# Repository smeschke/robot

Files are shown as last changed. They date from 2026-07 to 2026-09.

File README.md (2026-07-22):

Robot Platform 🛠️

Modular ESP32-based robot platform for outdoor navigation, motor control, and sensor integration.

This is a human-scale, differential-drive utility robot designed to move comfortably through real-world, ADA-compliant spaces at walking speed.

I chose 10-inch pneumatic tires so the robot can handle sidewalks, ramps, and grass reliably without suspension. The motors, gearboxes, and battery come from ride-on toys—they're inexpensive, readily available, and deliver excellent torque at low speeds.

The robot is controlled by an ESP32. The ESP32 uses ESPNOW to communicate with a manual joystick, or a computer. This allows the user to switch from 'auto' to 'manual' without touching any cords.

🔧 Technical Snapshot

The robot uses 550-type brushed DC motors with 100:1 reduction gearboxes driving 10-inch pneumatic wheels. It's powered by 12-volt, 7 amp-hour sealed lead-acid battery(s). Motor control is handled by BTS7960 H-bridge motor drivers.

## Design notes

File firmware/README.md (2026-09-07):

# Firmware ⚡

Arduino sketches for every ESP32 in the system — a sketch for each of the controllers, and a sketch for each of the boards on the robot. All of it is plain Arduino with no libraries beyond `esp_now.h` (plus a display library for the dual stick's screen). Everything talks ESP-NOW on channel 1, no encryption, packet types distinguished purely by length.

## Sketches

| Sketch | Flashes onto | Does |
|---|---|---|
| [`single_analog_stick_espnow.ino`](single_analog_stick_espnow.ino) | single stick controller | Streams drive packets every 5 ms |
| [`skidsteer_espnow.ino`](motor_receiver.ino) | robot — motor board | Arcade-mixed skid steer on four BTS7960 channels, with ramping and a 300 ms fail-safe stop |

## Setup

Standard ESP32 Arduino toolchain — install the ESP32 board package, pick your board, flash over USB. The controllers flash through the same USB-C port that powers them, no disassembly.

The only per-build configuration is MAC addresses: controllers send to hardcoded peers, so flash the robot boards first, grab each board's MAC from the serial monitor at boot, and paste them into the controller sketch (`robotMac` in the single stick; `motorMac` and `relayMac` in the dual stick). The robot boards need no controller config — they auto-register whichever controller they hear first.

Wiring diagrams, BOMs, and protocol documents are in [`build_documents/`](../build_documents/).

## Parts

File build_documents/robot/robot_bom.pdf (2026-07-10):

E S P - N O W C O N T R O L P R O T O C O L · T E A R D O W N C O N V E N T I O N

# Robot — Bill of Materials

ROBOT

4×10" differential-drive base

Part | Qty | Unit Cost | Total Cost
550-size 12V gearmotor (~100W) | 4 | $18.00 | $72.00
BTS7960 (IBT-2) H-bridge driver | 4 | $7.00 | $28.00
10" pneumatic tire + hub | 4 | $14.00 | $56.00
12V 7Ah SLA battery | 2 | $20.00 | $40.00
ESP32 receiver board (ESP-NOW) | 1 | $6.00 | $6.00
Frame/chassis stock, fasteners | 1 | $30.00 | $30.00
Wiring/fusing/connectors | 1 | $10.00 | $10.00
Total Build Cost | | | $242.00

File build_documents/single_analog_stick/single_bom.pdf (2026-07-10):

E S P - N O W C O N T R O L P R O T O C O L · T E A R D O W N C O N V E N T I O N

# Single Analog Stick Controller — Bill of Materials

CONTROLLER 1

Minimal one-way sender — drive + lights

Part | Qty | Unit Cost | Total Cost
ESP32 DevKit V1 (or XIAO-C3) | 1 | $6.00 | $6.00
KY-023 joystick module | 1 | $2.00 | $2.00
3D printed enclosure (PLA) | 1 | $2.00 | $2.00
Wire/connectors/hardware | 1 | $3.00 | $3.00
Total Build Cost | | | $13.00

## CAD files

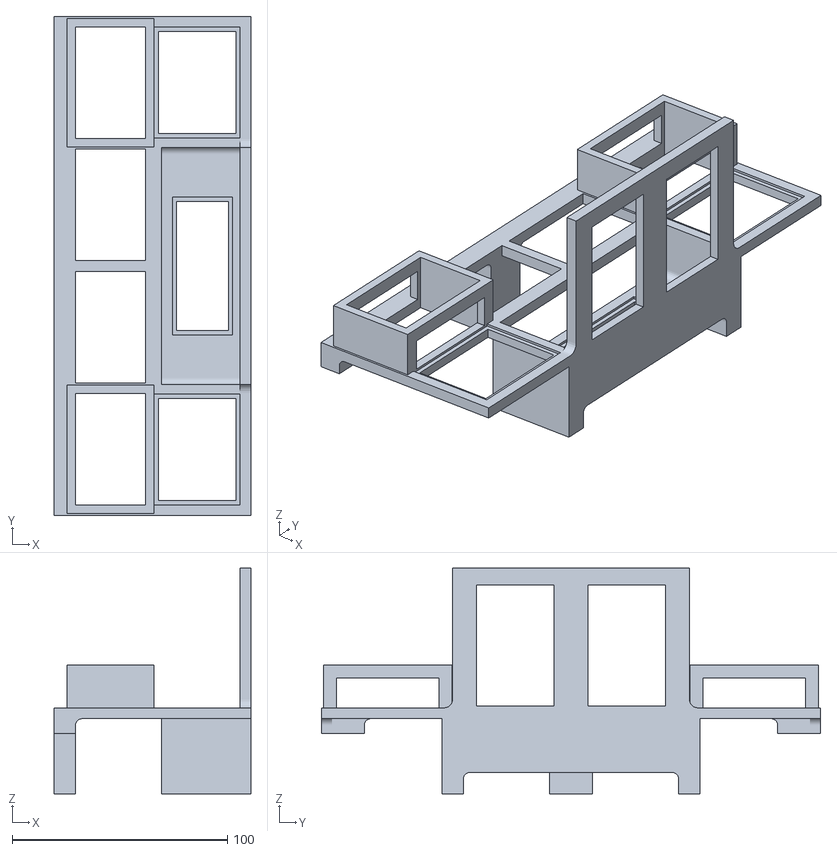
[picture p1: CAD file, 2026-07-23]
build_documents/robot/driver_board.stl
91.5 x 232.0 x 105.0

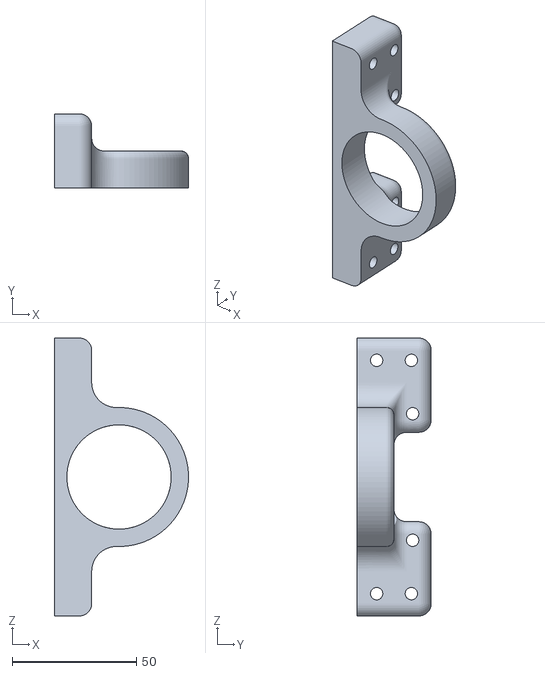
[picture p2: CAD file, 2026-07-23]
build_documents/robot/wheel_mount.stl
54.0 x 30.0 x 112.0

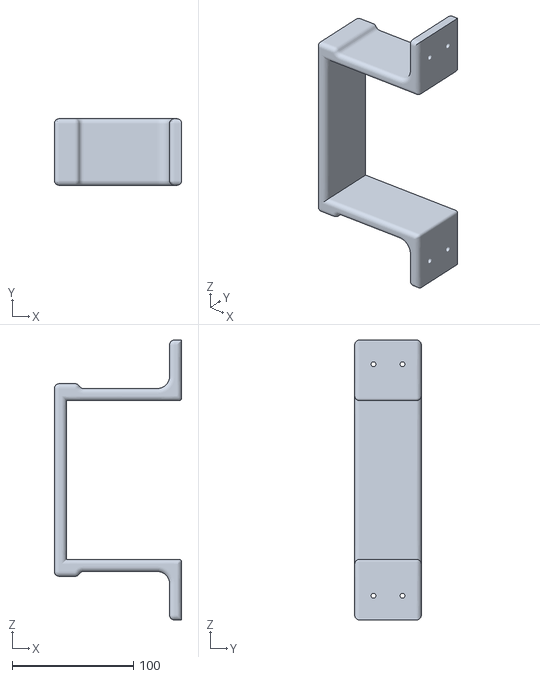
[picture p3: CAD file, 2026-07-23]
build_documents/robot/battery_holder.stl
105.0 x 55.0 x 231.0

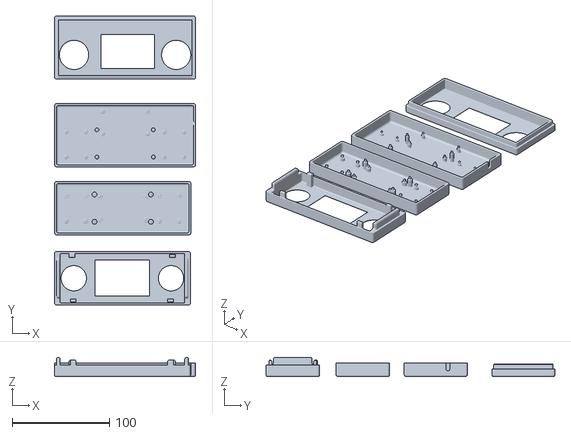
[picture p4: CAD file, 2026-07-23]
build_documents/robot/dual_joystick_controller_2_inch_screen.stl
145.3 x 297.0 x 20.0

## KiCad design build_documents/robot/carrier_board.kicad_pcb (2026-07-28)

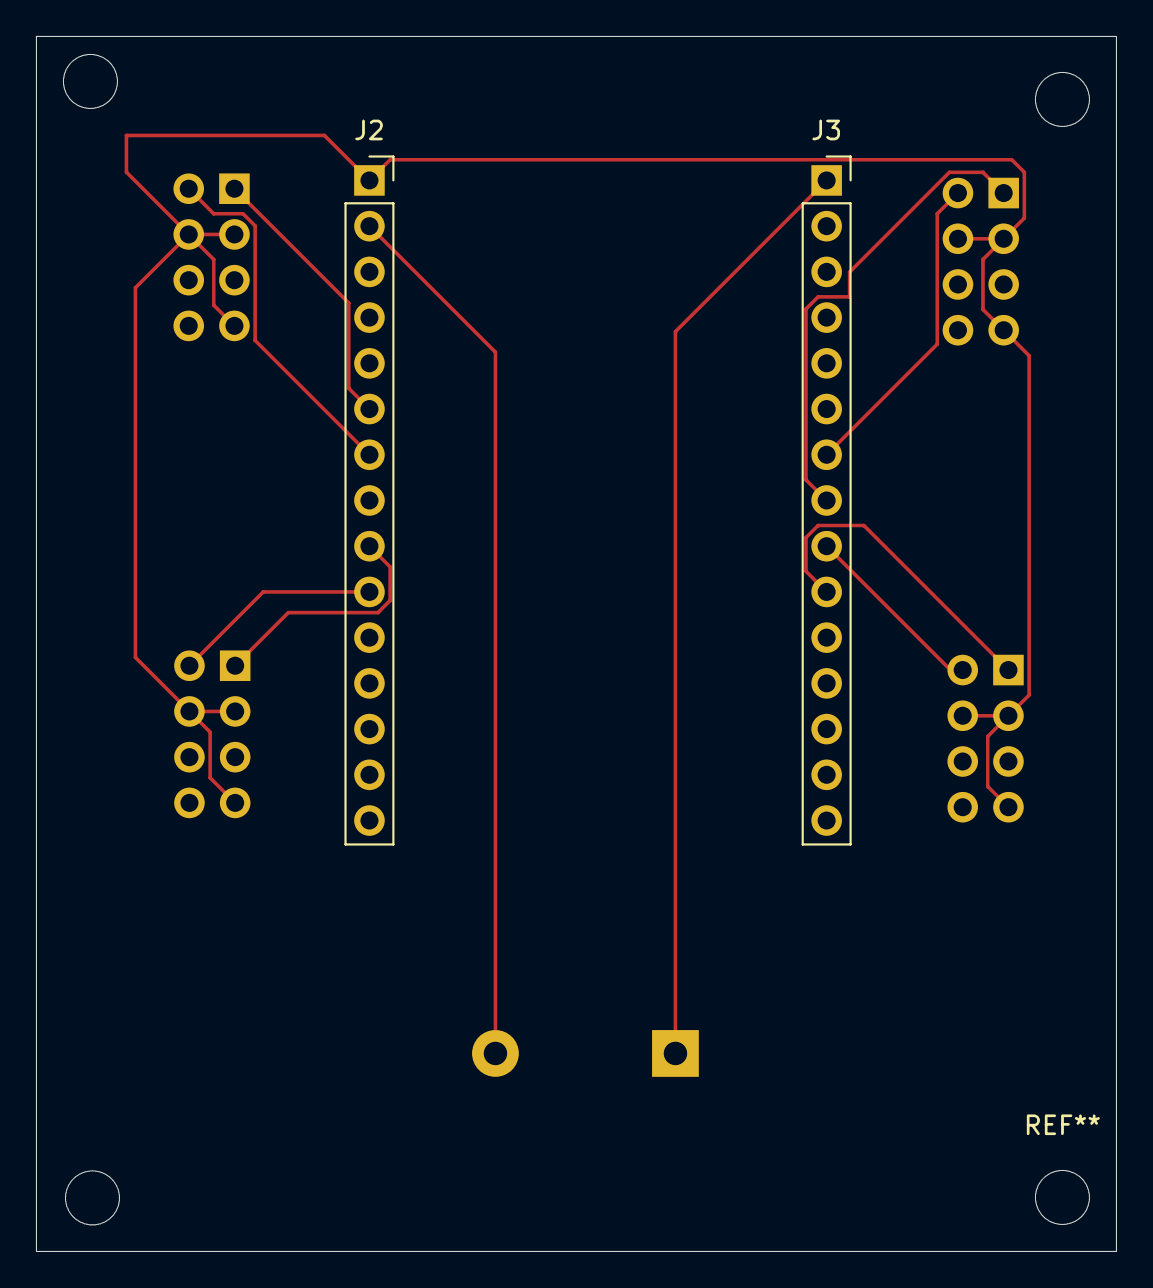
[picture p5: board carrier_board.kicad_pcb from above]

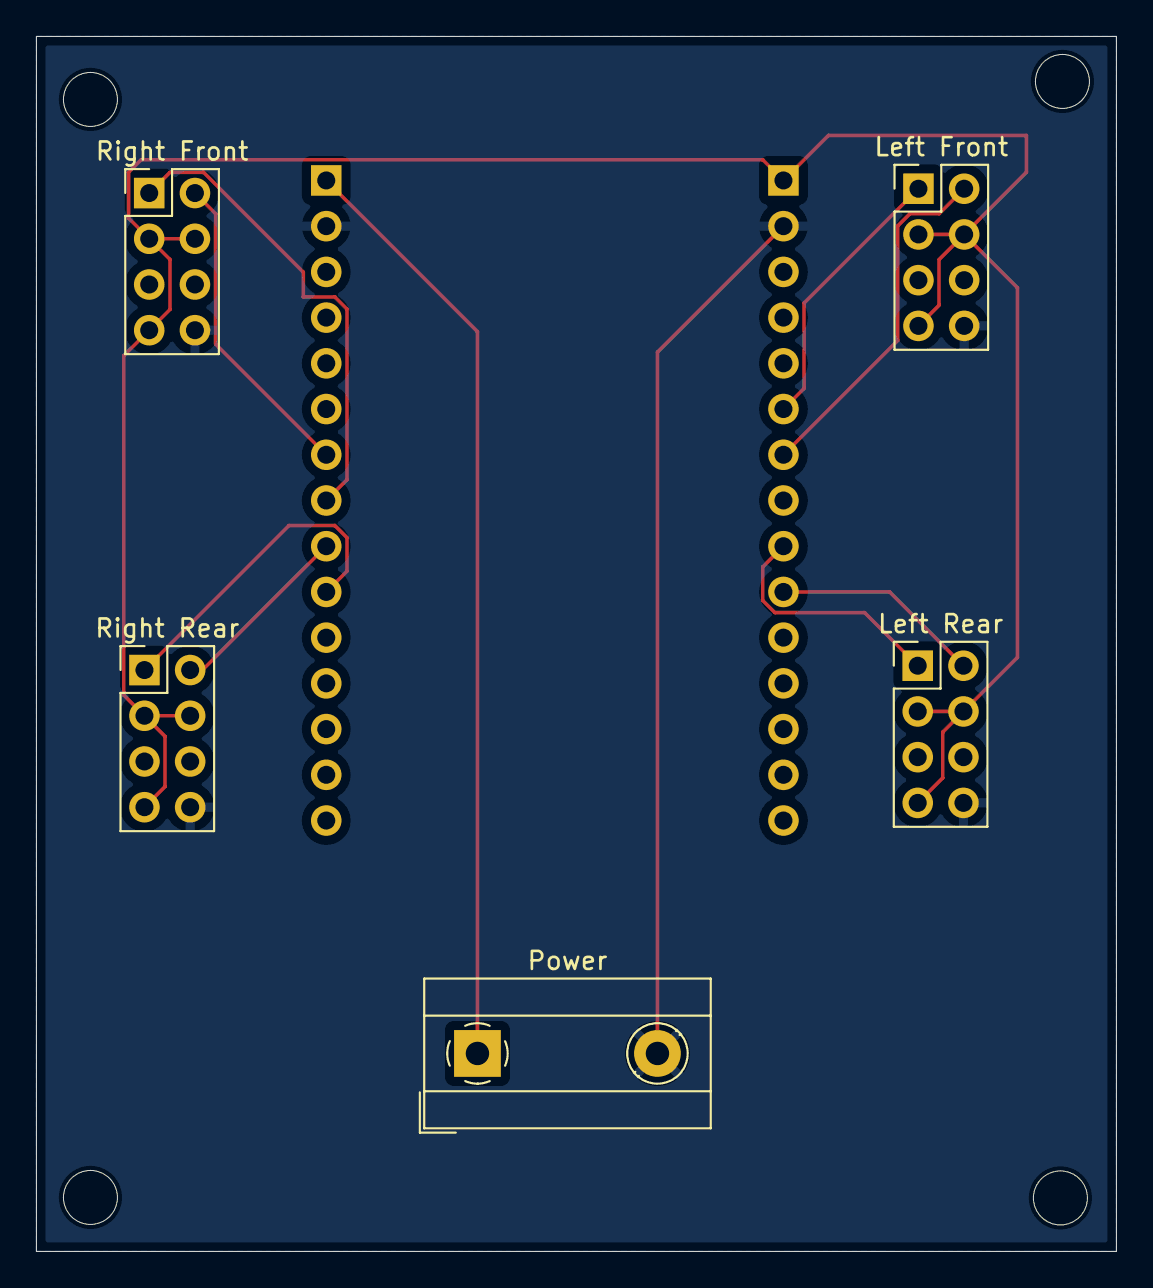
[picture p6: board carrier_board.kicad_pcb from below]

Board: 2 copper layers, 60.0 x 67.5 mm, 7 parts (5 on the bottom side), 11 nets.

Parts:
J2, J3: Conn_01x15; PinSocket_1x15_P2.54mm_Vertical
Left Front: Conn_02x04_Odd_Even; PinHeader_2x04_P2.54mm_Vertical
Left Rear: Conn_02x04_Odd_Even; PinHeader_2x04_P2.54mm_Vertical
Power: Screw_Terminal_01x02; TerminalBlock_MetzConnect_Type067_RT01902HDWC_1x02_P10.00mm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
Right Front: Conn_02x04_Odd_Even; PinHeader_2x04_P2.54mm_Vertical
Right Rear: Conn_02x04_Odd_Even; PinHeader_2x04_P2.54mm_Vertical

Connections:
/+3V3: J2.1, Left Front.3, Left Front.4, Left Front.7, Left Rear.3, Left Rear.4, Left Rear.7, Right Front.3, Right Front.4, Right Front.7, Right Rear.3, Right Rear.4, Right Rear.7
/+5V: J3.1, Power.1
/GND: J2.2, J3.2, Left Front.8, Left Rear.8, Power.2, Right Front.8, Right Rear.8
/GPIO16: J2.6, Left Front.1
/GPIO17: J2.7, Left Front.2
/GPIO18: J2.9, Left Rear.1
/GPIO19: J2.10, Left Rear.2
/GPIO25: J3.8, Right Front.1
/GPIO26: J3.7, Right Front.2
/GPIO32: J3.10, Right Rear.1
/GPIO33: J3.9, Right Rear.2

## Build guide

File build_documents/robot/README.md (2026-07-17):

# The Robot 🤖

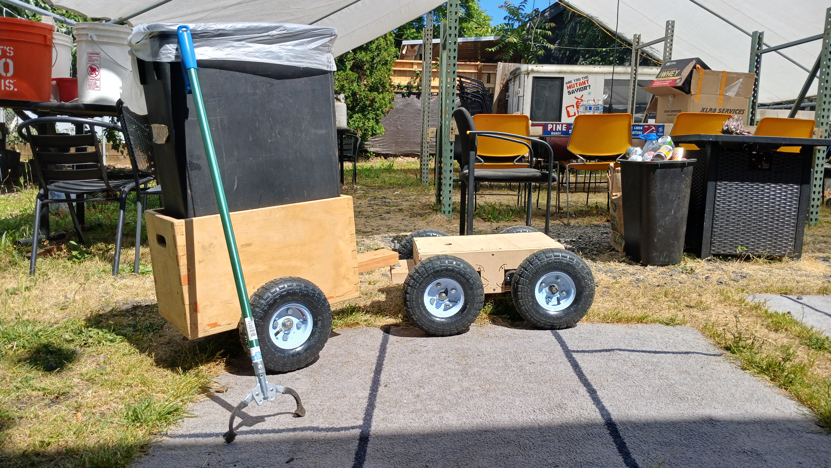
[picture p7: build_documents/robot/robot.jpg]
robot


Human-scale differential-drive utility robot built from ride-on toy parts: 550-type brushed motors with 100:1 gearboxes on 10-inch pneumatic wheels, powered by 12 V 7 Ah sealed lead-acid, driven by BTS7960 H-bridges. Ride-on toy drivetrains are cheap, everywhere, and geared for exactly this job — high torque at walking speed. The pneumatic tires handle sidewalks, ramps, and grass without any suspension, and it'll tow a cart.

## Architecture

There's no single robot brain — it's two independent ESP32s, each listening on ESP-NOW:

- **Motor board** ([`firmware/skidsteer_espnow.ino`](../../firmware/skidsteer_espnow.ino)) — receives the drive stream, does the skid-steer mixing, runs four BTS7960 channels.
- **Relay board** ([`firmware/relay_receiver.ino`](../../firmware/relay_receiver.ino)) — receives light events, drives two relays (left/right lights) for latched headlights and 2-second momentary turn signals.

Receivers tell packets apart purely by length (12-byte drive, 5-byte light event), so both boards can share the airwaves without a header byte or any routing. Anything that speaks the protocol can drive it — the single stick, the dual stick, or a computer through a reflashed controller — and switching between manual and auto control never involves touching a cord.

## Drive behavior

The motor board turns the joystick stream into arcade-mixed skid steer (throttle ± turn), with two safety behaviors worth knowing:

- **Fail-safe stop.** If no drive packet arrives for 300 ms, targets go to zero. The controller streams every 5 ms, so this only trips when the link is actually gone.
- **Ramping.** Motor output moves toward the target 1 PWM count every 3 ms (~0 to full in 0.75 s), so a stick flick doesn't dump full torque into the drivetrain — and the fail-safe stop is a controlled ramp-down, not a faceplant.

There's also a ~20% stick deadzone in the mixer, so the robot stays genuinely still at center.

## Lights

The relay board latches headlights on/off and fires momentary turn signals, deduping the controller's burst-resends by sequence number. A turn signal on one side never touches the other side's relay, and when it expires the relay reverts to the headlight state. Every ~500 ms it sends a heartbeat back (RSSI, relay state, uptime) — that's what feeds the dual stick controller's HUD. Controllers are auto-registered: first packet heard from a MAC becomes the peer, no pairing step.

## Build docs

- [Bill of materials](robot_bom.pdf)
- [Wiring diagram](robot_wiring_diagram.png)
- [Protocol details](robot_protocol.pdf)
- [STL files](stl_for_robot.md)

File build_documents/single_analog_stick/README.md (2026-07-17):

# Single Analog Stick Controller 🕹️

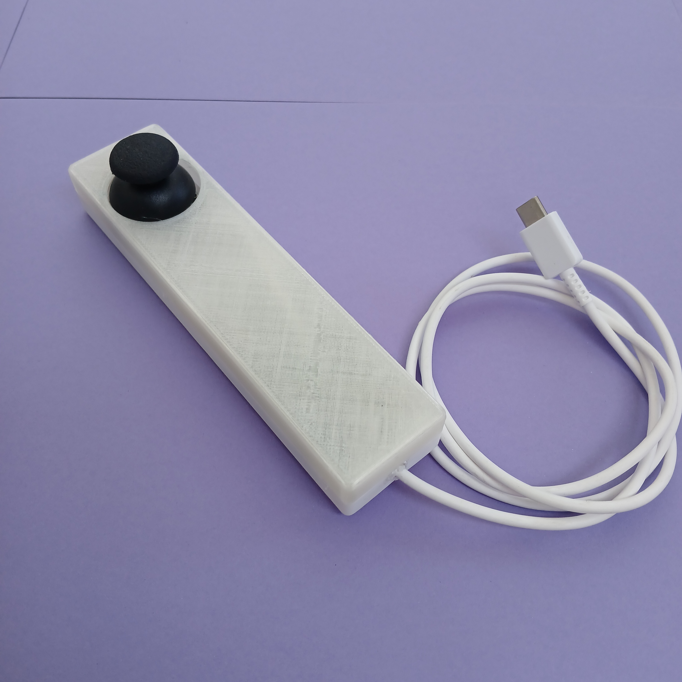
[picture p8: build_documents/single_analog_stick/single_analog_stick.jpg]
single analog stick controller


One-handed controller for the robot: an ESP32, an analog thumbstick, and a 3D-printed enclosure. Thumb handles steering and throttle; clicking the stick cycles the speed cap 25% → 50% → 75% → 100%. Driving one-handed leaves your other hand free to load items onto the robot, hold a coffee, or open doors.

There's no onboard battery — the controller runs off its USB-C cable, so plug it into a pocket USB battery pack in the field, or any phone charger at the bench.

## USB-C goes straight to the ESP32

The USB-C port is wired to the ESP32's USB interface, not just power. Plug the controller into a computer and you have serial and flashing access — no disassembly, no test pads, no jig. So:

- Reflash it as a serial-to-ESP-NOW bridge and drive the robot from any computer that can open a serial port. Flash the stock firmware back when done.
- Need an ESP32 for a minute? This is one, in a case.

## Protocol

ESP-NOW, channel 1, addressed to the robot's MAC. Packets every 5 ms:

```c
typedef struct __attribute__((packed)) {
  uint16_t x;    // 0–4095, center 2048
  uint16_t y;    // 0–4095, center 2048
  uint32_t seq;  // packet counter
  uint32_t ms;   // sender uptime
} JoyPacket;
```

Stick auto-centers on boot, ±40-count deadband. Speed scaling happens sender-side, so the packet carries final values and the robot firmware stays simple. `seq`/`ms` let the receiver drop stale packets.

Firmware is ~100 lines of plain Arduino, no libraries beyond `esp_now.h`: [`firmware/single_analog_stick_espnow.ino`](../../firmware/single_analog_stick_espnow.ino). Retarget it by changing one MAC address.

## Build docs

- [Bill of materials](single_bom.pdf)
- [Wiring diagram](single_wiring_diagram.png) — three analog pins plus power
- [Protocol details](single_protocol.pdf)
- [STL files](stl_for_signle_stick.md)

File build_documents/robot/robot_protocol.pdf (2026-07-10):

E S P - N O W C O N T R O L P R O T O C O L · T E A R D O W N C O N V E N T I O N

# The Robot

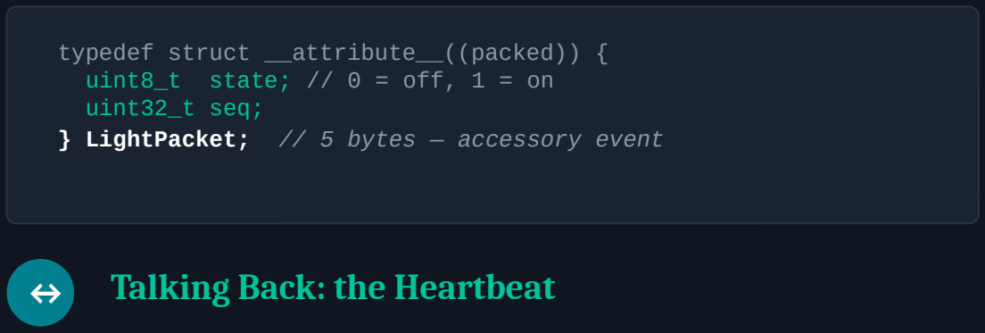
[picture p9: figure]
typedef struct __attribute__((packed)) { uint8_t state; // 0 = off, 1 = on uint32_t seq;; ↔ Talking Back: the Heartbeat

02 / 04

## ⚙ Fixed Firmware, Two Receiver Boards

All devices are locked to a fixed WiFi channel (channel 1) so they can hear each other without joining a network. Peers are registered explicitly via esp_now_add_peer() using each other's hardcoded MAC address — clean unicast, no broadcast noise.

▸ Motor receiver — drives the motors from continuous drive packets
▸ Relay receiver — switches lights/accessories from one-shot events

### Telling Packets Apart — By Length

Each function gets its own small, fixed-size, packed C struct. The receiver tells packet types apart by length — a zero-overhead form of message typing that needs no

} LightPacket; // 5 bytes — accessory event

The motor receiver sends a periodic heartbeat packet back to any listening controller, roughly every 500ms — RSSI, relay state, uptime. A screen-equipped controller renders this as a live HUD; a simpler controller just never asks for it. The robot doesn't need to know or care which is connected.

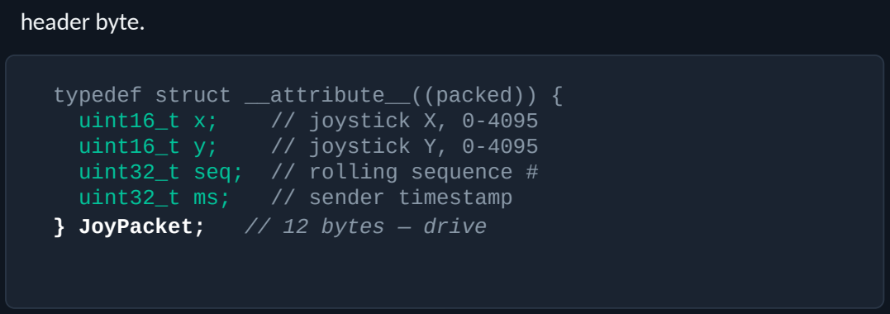
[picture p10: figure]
header byte.; typedef struct __attribute__((packed)) {; uint16_t x;; // joystick X, 0-4095; uint16_t y;; // joystick Y, 0-4095; uint32_t seq; // rolling sequence #; uint32_t ms;; // sender timestamp; } JoyPacket;; // 12 bytes — drive

### Reliability, Handled at the Application Layer

▸ Continuous streams (drive) are self-healing — a dropped packet is superseded 5ms later; a receiver-side timeout is a fail-safe stop
▸ One-shot events (light toggles) are made reliable by resending a few times in a burst rather than waiting on an ACK

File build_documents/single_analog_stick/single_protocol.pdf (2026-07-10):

E S P - N O W C O N T R O L P R O T O C O L · T E A R D O W N C O N V E N T I O N

# Single Analog Stick Controller

03 / 04

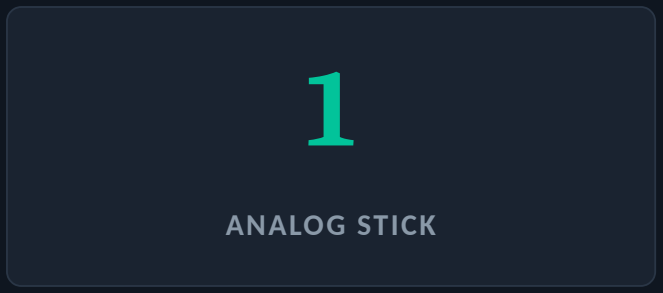
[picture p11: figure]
ANALOG STICK
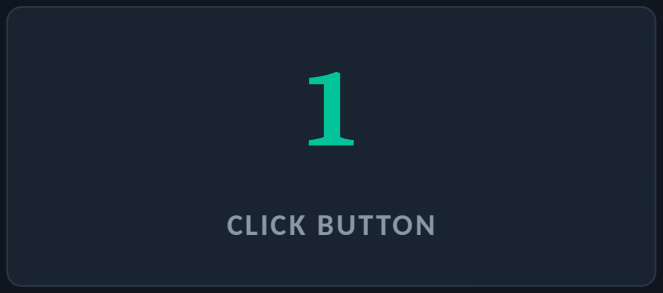
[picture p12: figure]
CLICK BUTTON
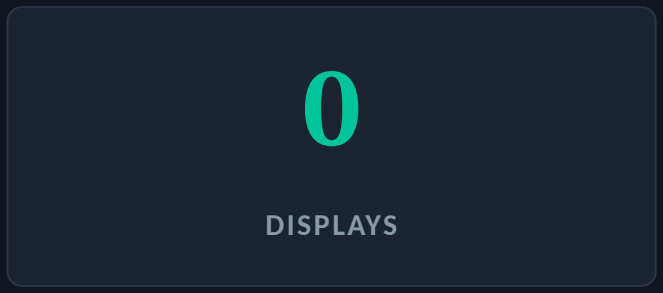
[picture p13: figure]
DISPLAYS

This is the minimal controller — one analog stick, one click button, no display. It only ever sends; it never listens for anything back from the robot.

## Behavior

Joystick X/Y → packed into a JoyPacket and sent to the robot continuously (~every 5ms)

Single click cycles four drive speed presets (25% / 50% / 75% / 100%)

Double click (2nd click within ~350ms) fires a one-shot LightPacket toggle

### Why It's Built This Way

One-way, fire-and-forget — the robot never talks back to this controller. One physical button drives two logically distinct systems (speed and lights) using nothing more than a debounce timer and a click-timing window in software. No extra hardware required.

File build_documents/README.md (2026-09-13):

# Build Documents 📐

Everything you need to build the robot and its controller.

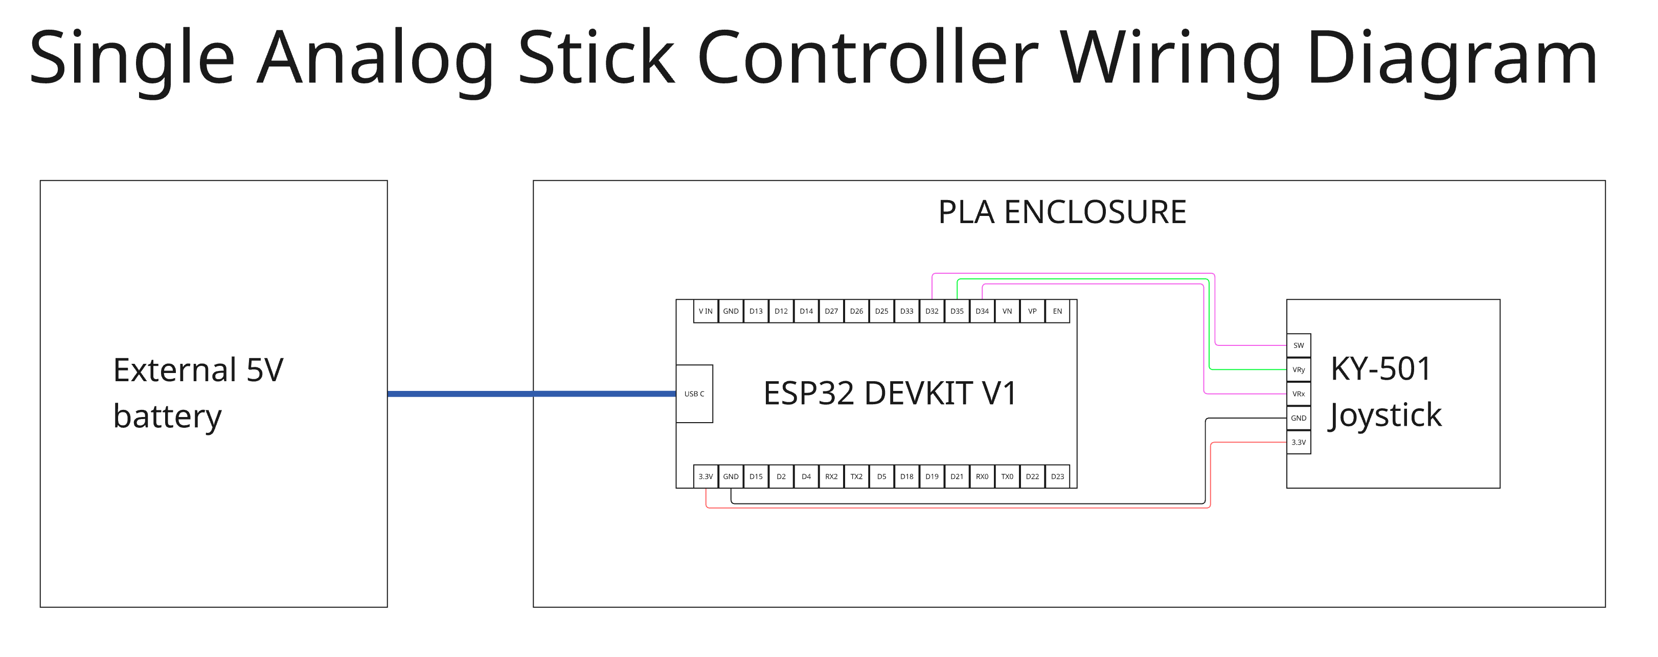
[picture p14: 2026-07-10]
build_documents/single_analog_stick/single_wiring_diagram.png

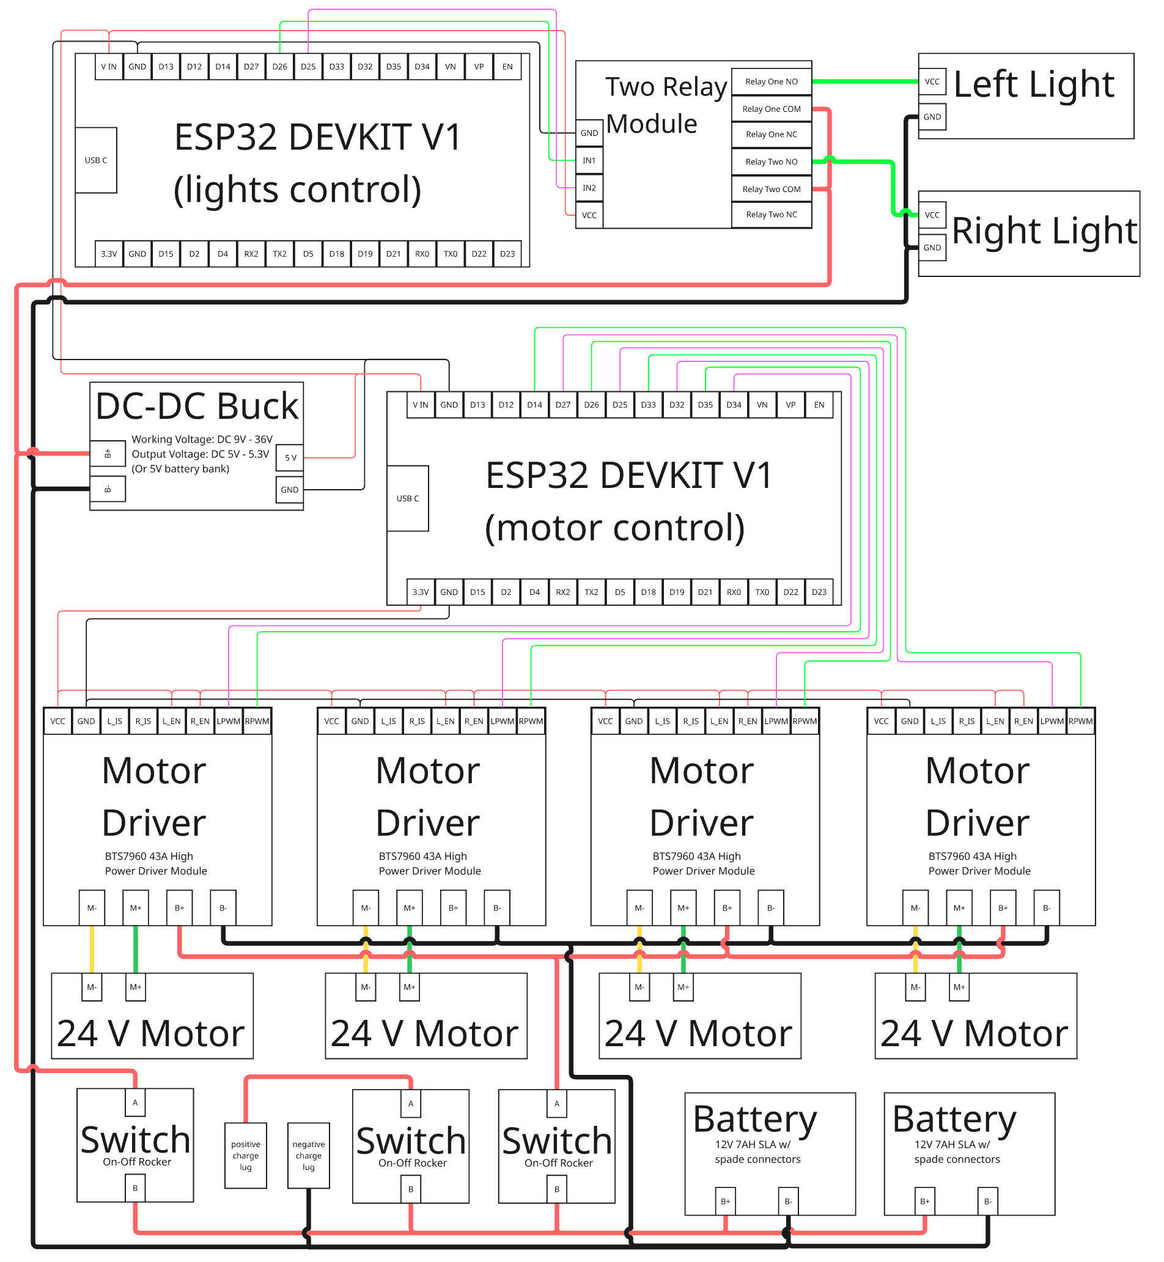
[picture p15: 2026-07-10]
build_documents/robot/robot_wiring_diagram.png

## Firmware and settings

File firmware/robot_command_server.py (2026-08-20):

#!/usr/bin/env python3
"""
robot_command_server.py -- runs on the Pi. Receives drive commands
("FWD", "REV", "SPIN <nx>", "STOP") over a plain TCP socket and forwards
motion to the ESP-NOW sender sketch over serial at 20 Hz.

No camera/video code here at all -- video is your problem now (phone,
Zoom, a second stream, whatever). This just drives the motors.

Motion logic (Link, Runner, spin_plan) is unchanged from llama_teleop.py --
it still talks "<left> <right>\n" to the ESP32 sender over serial.

  python3 robot_command_server.py --port /dev/ttyUSB0
  python3 robot_command_server.py --dry-run
"""

import argparse
import glob
import select
import socket
import threading
import time

try:
    import serial
except ImportError:
    serial = None

DEFAULT_CONTROL_PORT = 8091

SPIN_PWM_CENTER = 60
SPIN_PWM_EDGE = 160
SPIN_TIME_CENTER = 0.12
SPIN_TIME_EDGE = 0.5
CENTER_BAND = 1.0 / 3.0
PWM_SCALE = 0.8

MAX_PWM = 255              # hard ceiling -- client speed tops out here
FORWARD_MS = 250           # each FWD command drives for this long
FORWARD_STEER_GAIN = 0.6   # how much the nx argument biases L/R
REVERSE_MS = 300           # each REV command drives for this long

SILENCE_TIMEOUT_S = 1.0    # no command received for this long -> PWM 0,0

KEEPALIVE_S = 0.15
BOOT_WAIT_S = 2.0

STATUS_PUSH_S = 0.1


# ---------------------------------------------------------------- plan

def pwm(value):
    return int(round(value * PWM_SCALE))


def spin_plan(nx):
    """nx in [-1, 1]: sign is direction, magnitude is how hard/long to spin."""
    nx = max(-1.0, min(1.0, nx))
    off = abs(nx)
    t = round(SPIN_TIME_CENTER + (SPIN_TIME_EDGE - SPIN_TIME_CENTER) * off, 2)
    ramp = 0.0 if off <= CENTER_BAND else (off - CENTER_BAND) / (1.0 - CENTER_BAND)
    p = pwm(SPIN_PWM_CENTER + (SPIN_PWM_EDGE - SPIN_PWM_CENTER) * ramp)
    if nx >= 0:
        return [(-p, p, t, "spin left")]
    return [(p, -p, t, "spin right")]


def print_plan(segs, label):
    print()
    print("-" * 44)
    print(f"{label}    [{time.strftime('%H:%M:%S')}]")
    if not segs:
        print("  (no motion)")
    for i, (l, r, t, seg_label) in enumerate(segs, 1):
        print(f"  {i}. LPWM {l:4d}  RPWM {r:4d}  {t:4.2f} s   ({seg_label})")
    print("-" * 44)


# ---------------------------------------------------------------- link

class Link:
    """Serial connection to the ESP-NOW sender sketch."""

    def __init__(self, port, baud=115200, dry_run=False):
        self.dry_run = dry_run or serial is None
        self.ser = None
        self.lock = threading.Lock()
        if self.dry_run:
            if serial is None and not dry_run:
                print("pyserial not installed -- running dry. "
                      "pip3 install pyserial")
            print("[dry run] commands will only be printed")
            return
        if port == "auto":
            found = (sorted(glob.glob("/dev/ttyUSB*"))
                     + sorted(glob.glob("/dev/ttyACM*")))
            if not found:
                raise SystemExit("no /dev/ttyUSB* or /dev/ttyACM* found; "
                                 "pass --port or use --dry-run")
            port = found[0]
        self.ser = serial.Serial(port, baud, timeout=0.1)
        print(f"serial: {port} @ {baud}, waiting {BOOT_WAIT_S}s for ESP32 boot")
        time.sleep(BOOT_WAIT_S)
        self.ser.reset_input_buffer()

    def send(self, left, right):
        left = max(-255, min(255, int(left)))
        right = max(-255, min(255, int(right)))
        line = f"{left} {right}\n"
        if self.dry_run:
            print(f"  >> {line.strip()}")
            return
        with self.lock:
            self.ser.write(line.encode())
            self.ser.flush()

    def stop(self):
        self.send(0, 0)

    def close(self):
        try:
            self.stop()
            time.sleep(0.05)
        finally:
            if self.ser:
                self.ser.close()


# ------------------------------------------------------------- runner

class Runner:
    def __init__(self, link):
        self.link = link
        self.abort = threading.Event()
        self.thread = None
        self.status = "idle"

    @property
    def busy(self):
        return self.thread is not None and self.thread.is_alive()

    def run(self, segs):
        self.cancel()
        self.abort.clear()
        self.thread = threading.Thread(target=self._worker, args=(segs,),
                                       daemon=True)
        self.thread.start()

    def run_one(self, l, r, seconds, label):
        self.run([(l, r, seconds, label)])

    def cancel(self):
        if self.busy:
            self.abort.set()
            self.thread.join(timeout=1.0)
        self.link.stop()
        self.status = "idle"

    def _worker(self, segs):
        try:
            for l, r, t, label in segs:
                self.status = f"{label} L{l} R{r} {t:.2f}s"
                end = time.time() + t
                while time.time() < end:
                    if self.abort.is_set():
                        return
                    self.link.send(l, r)
                    time.sleep(min(KEEPALIVE_S, max(0.0, end - time.time())))
        finally:
            self.link.stop()
            self.status = "idle"


# ------------------------------------------------------------ networking

def send_all(conn, data):
    conn.sendall(data)


def control_client_loop(conn, runner, state):
    conn.setsockopt(socket.IPPROTO_TCP, socket.TCP_NODELAY, 1)

    def status_pusher(stop_evt):
        try:
            while not stop_evt.is_set():
                moving = 1 if runner.busy else 0
                line = f"STATUS {moving}|{runner.status}\n"
                send_all(conn, line.encode())
                time.sleep(STATUS_PUSH_S)
        except (BrokenPipeError, ConnectionResetError, OSError):
            pass

    stop_evt = threading.Event()
    pusher = threading.Thread(target=status_pusher, args=(stop_evt,), daemon=True)
    pusher.start()

    def handle(line):
        state["last_cmd"] = time.time()
        parts = line.split()
        if not parts:
            return
        cmd = parts[0]
        if cmd == "FWD":
            nx = float(parts[1]) if len(parts) >= 2 else 0.0
            speed = float(parts[2]) if len(parts) >= 3 else MAX_PWM
            nx = max(-1.0, min(1.0, nx))
            speed = max(0.0, min(MAX_PWM, speed))
            l = int(round(speed * (1 - nx * FORWARD_STEER_GAIN)))
            r = int(round(speed * (1 + nx * FORWARD_STEER_GAIN)))
            label = f"forward nx={nx:+.2f} speed={speed:.0f}"
            print_plan([(-l, -r, FORWARD_MS / 1000.0, label)], label)
            runner.run_one(-l, -r, FORWARD_MS / 1000.0, label)
        elif cmd == "REV":
            speed = float(parts[1]) if len(parts) >= 2 else MAX_PWM
            speed = max(0.0, min(MAX_PWM, speed))
            rev_pwm = int(round(speed))
            label = f"reverse speed={speed:.0f}"
            print_plan([(rev_pwm, rev_pwm, REVERSE_MS / 1000.0, label)], label)
            runner.run_one(rev_pwm, rev_pwm, REVERSE_MS / 1000.0, label)
        elif cmd == "SPIN" and len(parts) >= 2:
            nx = float(parts[1])
            speed = float(parts[2]) if len(parts) >= 3 else MAX_PWM
            speed = max(0.0, min(MAX_PWM, speed))
            scale = speed / MAX_PWM
            segs = spin_plan(nx)
            segs = [(int(round(l * scale)), int(round(r * scale)), t, lbl)
                    for l, r, t, lbl in segs]
            print_plan(segs, f"spin nx={nx:+.2f} speed={speed:.0f}")
            runner.run(segs)
        elif cmd == "STOP":
            runner.cancel()
            print("STOP")

    buf = b""
    try:
        while True:
            chunk = conn.recv(4096)
            if not chunk:
                break
            buf += chunk

            # drain whatever else is already sitting in the socket, non-blocking,
            # so a burst of queued commands collapses to just the newest one
            while True:
                ready, _, _ = select.select([conn], [], [], 0)
                if not ready:
                    break
                more = conn.recv(4096)
                if not more:
                    break
                buf += more

            *complete, buf = buf.split(b"\n")
            lines = [ln.decode().strip() for ln in complete if ln.strip()]
            if not lines:
                continue
            for stale in lines[:-1]:
                state["last_cmd"] = time.time()  # still counts as a live client
            handle(lines[-1])
    except (BrokenPipeError, ConnectionResetError, OSError):
        pass
    finally:
        stop_evt.set()
        runner.cancel()  # safety: control link dropped -> stop the robot
        conn.close()


def silence_watchdog(link, state):
    """If no command has been received for SILENCE_TIMEOUT_S, force PWM 0,0."""
    while True:
        if time.time() - state["last_cmd"] > SILENCE_TIMEOUT_S:
            link.stop()
        time.sleep(KEEPALIVE_S)


def accept_loop(sock, handler, *args):
    while True:
        conn, addr = sock.accept()
        print(f"client connected from {addr[0]}:{addr[1]} ({sock.getsockname()[1]})")
        threading.Thread(target=handler, args=(conn,) + args, daemon=True).start()


def main():
    ap = argparse.ArgumentParser()
    ap.add_argument("--port", default="auto",
                    help="serial port of the ESP32 sender, or 'auto'")
    ap.add_argument("--baud", type=int, default=115200)
    ap.add_argument("--dry-run", action="store_true")
    ap.add_argument("--host", default="0.0.0.0")
    ap.add_argument("--control-port", type=int, default=DEFAULT_CONTROL_PORT)
    args = ap.parse_args()

    link = Link(args.port, args.baud, args.dry_run)
    runner = Runner(link)
    state = {"last_cmd": time.time()}

    control_sock = socket.socket(socket.AF_INET, socket.SOCK_STREAM)
    control_sock.setsockopt(socket.SOL_SOCKET, socket.SO_REUSEADDR, 1)
    control_sock.bind((args.host, args.control_port))
    control_sock.listen(1)

    print(f"control listening on {args.host}:{args.control_port}")

    threading.Thread(target=silence_watchdog, args=(link, state), daemon=True).start()

    try:
        accept_loop(control_sock, control_client_loop, runner, state)
    except KeyboardInterrupt:
        pass
    finally:
        runner.cancel()
        link.close()


if __name__ == "__main__":
    main()

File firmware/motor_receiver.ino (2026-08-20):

// ===== R5D2 Robot: Motor Receiver (ESP-NOW, LEDC PWM) =====
//
// Wire format: DrivePacket{left, right} -- signed PWM per side, -255..255.
// Works with either a human joystick remote (which does its own arcade-
// drive mixing before sending) or a computer plugged into an ESP32 bridge
// (which can send raw left/right values directly). This receiver does no
// mixing -- it only ramps toward the commanded values (to protect the
// gearboxes from instant direction reversals) and writes PWM to the
// motors via the ESP32 LEDC peripheral. Stopping is just PWM 0; the
// motors' gear reduction holds them, so no active braking is needed.

#include <WiFi.h>
#include <esp_now.h>

// ================= Motor pins =================

// #define FL_LPWM 33
// #define FL_RPWM 25
// #define BL_LPWM 26
// #define BL_RPWM 32
//#define FL_LPWM 33
//#define FL_RPWM 32
//#define BL_LPWM 25
//#define BL_RPWM 26
//#define FR_LPWM 14
//#define FR_RPWM 27
//#define BR_LPWM 18
//#define BR_RPWM 19

#define FL_RPWM 16
#define FL_LPWM 17
#define BL_RPWM 18
#define BL_LPWM 19
#define FR_RPWM 32
#define FR_LPWM 33
#define BR_RPWM 25
#define BR_LPWM 26

// ================= LEDC settings =================
const int LEDC_FREQ_HZ  = 20000; // above audible range
const int LEDC_RES_BITS = 8;     // 0..255 duty, matches PWM range below

// ================= Settings =================
const int      RAMP_STEP      = 1;   // max PWM change per ramp tick
const uint32_t RAMP_DT_MS     = 3;   // ramp tick period
const uint32_t CMD_TIMEOUT_MS = 300; // stop if no packet received in this long

// ================= Wire format =================
typedef struct __attribute__((packed)) {
  int16_t left;   // -255..255
  int16_t right;  // -255..255
} DrivePacket;

// ================= State =================
int curL = 0, curR = 0;
volatile int tgtL = 0, tgtR = 0;
volatile uint32_t lastRecvMs = 0;
uint32_t lastRampMs = 0;

void setAll(int l, int r) {
  l = constrain(l, -255, 255);
  r = constrain(r, -255, 255);

  if (l >= 0) {
    ledcWrite(FL_LPWM, l); ledcWrite(FL_RPWM, 0);
    ledcWrite(BL_LPWM, l); ledcWrite(BL_RPWM, 0);
  } else {
    ledcWrite(FL_LPWM, 0); ledcWrite(FL_RPWM, -l);
    ledcWrite(BL_LPWM, 0); ledcWrite(BL_RPWM, -l);
  }

  if (r >= 0) {
    ledcWrite(FR_LPWM, r); ledcWrite(FR_RPWM, 0);
    ledcWrite(BR_LPWM, r); ledcWrite(BR_RPWM, 0);
  } else {
    ledcWrite(FR_LPWM, 0); ledcWrite(FR_RPWM, -r);
    ledcWrite(BR_LPWM, 0); ledcWrite(BR_RPWM, -r);
  }
}

// ================= ESP-NOW receive =================
void onRecv(const esp_now_recv_info_t* info, const uint8_t* data, int len) {
  if (len != sizeof(DrivePacket)) return;

  DrivePacket p;
  memcpy(&p, data, sizeof(p));

  tgtL = constrain((int)p.left, -255, 255);
  tgtR = constrain((int)p.right, -255, 255);
  lastRecvMs = millis();
}

// ================= Setup =================
void setup() {
  Serial.begin(115200);

  ledcAttach(FL_LPWM, LEDC_FREQ_HZ, LEDC_RES_BITS);
  ledcAttach(FL_RPWM, LEDC_FREQ_HZ, LEDC_RES_BITS);
  ledcAttach(BL_LPWM, LEDC_FREQ_HZ, LEDC_RES_BITS);
  ledcAttach(BL_RPWM, LEDC_FREQ_HZ, LEDC_RES_BITS);
  ledcAttach(FR_LPWM, LEDC_FREQ_HZ, LEDC_RES_BITS);
  ledcAttach(FR_RPWM, LEDC_FREQ_HZ, LEDC_RES_BITS);
  ledcAttach(BR_LPWM, LEDC_FREQ_HZ, LEDC_RES_BITS);
  ledcAttach(BR_RPWM, LEDC_FREQ_HZ, LEDC_RES_BITS);

  setAll(0, 0);

  WiFi.mode(WIFI_STA);
  WiFi.setSleep(false);

  esp_now_init();
  esp_now_register_recv_cb(onRecv);

  Serial.println("Robot Ready.");
}

// ================= Loop =================
void loop() {
  uint32_t now = millis();

  if (now - lastRecvMs > CMD_TIMEOUT_MS) {
    tgtL = 0;
    tgtR = 0;
  }

  if (now - lastRampMs >= RAMP_DT_MS) {
    lastRampMs = now;
    curL += constrain(tgtL - curL, -RAMP_STEP, RAMP_STEP);
    curR += constrain(tgtR - curR, -RAMP_STEP, RAMP_STEP);
    setAll(curL, curR);
  }
}

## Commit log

2026-06-22 Add joystick sender with LED control and ESP-NOW
2026-07-22 Update README for clarity on ESP32 control
2026-08-20 Update motor receiver to use LEDC for PWM control
2026-08-20 Refactor joystick sender for arcade-drive mixing
    Updated joystick control logic to compute left/right motor PWM directly in the sender. Changed packet structure to DrivePacket for sending motor commands.
